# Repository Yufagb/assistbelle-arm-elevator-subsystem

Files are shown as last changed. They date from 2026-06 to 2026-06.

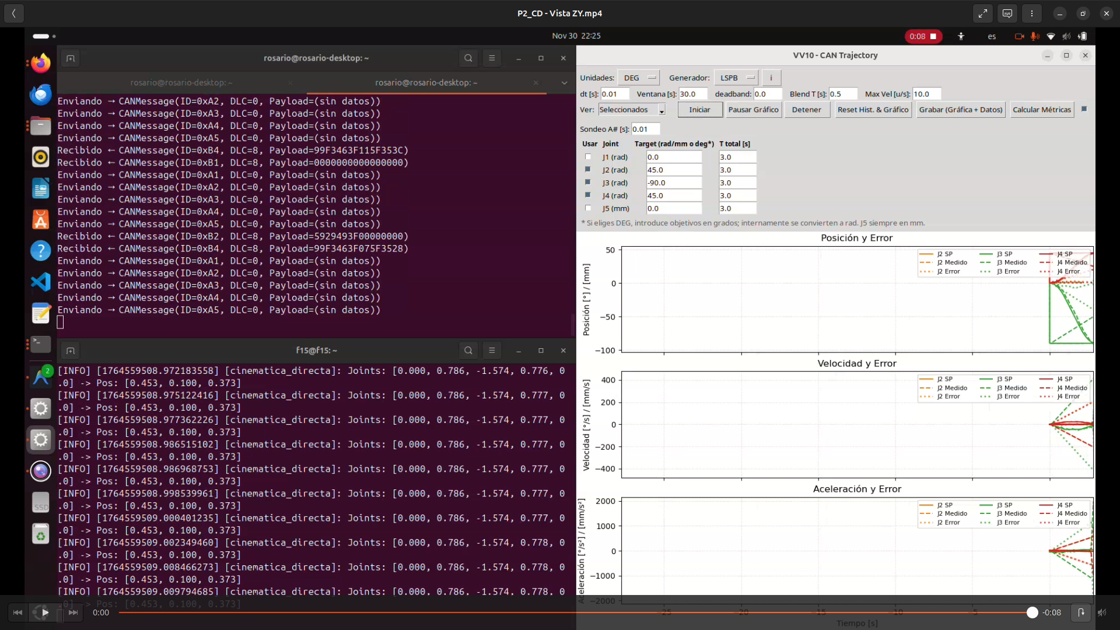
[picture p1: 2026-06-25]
validation/kinematics_tests/figures/CD_P2_Consola.png

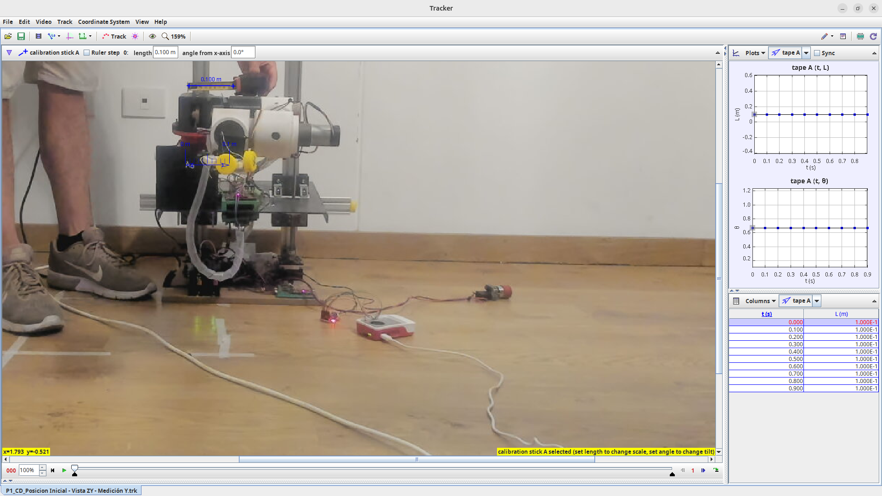
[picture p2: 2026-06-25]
validation/kinematics_tests/figures/CD_P1_VistaZY_MedicionY.png

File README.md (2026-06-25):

<!-- SPDX-License-Identifier: CC-BY-4.0 -->

# Assistbelle robotic arm and elevator subsystem

Open-source HardwareX publication package for the **robotic arm and vertical elevator subsystem** of Assistbelle, intended for controlled laboratory experiments on the manipulation and transport of medical supplies.

This repository contains the hardware documentation, firmware, ROS 2 software, electronics documentation, validation material and publication support files needed to reproduce and evaluate the arm/elevator subsystem.

## Authors

- Yuri Fabian Vilela Obando
- Luciano Matteo Vergani Api

## Scope

This repository covers:

- robotic arm subsystem;
- vertical elevator / prismatic axis;
- ESP32 firmware for distributed joint control;
- CAN / SocketCAN communication;
- ROS 2 control and validation utilities;
- electronics documentation, pinouts, power distribution and schematics;
- bill of materials (BOM);
- validation documentation and curated evidence structure;
- documentation and paper-support material for HardwareX.

## Out of scope

The current public package does **not** cover:

- autonomous navigation;
- the complete mobile base;
- the storage module;
- real clinical validation or certified medical-device use.

The system must be interpreted as a **laboratory prototype** for controlled validation, not as a clinically approved device.

## Quick start

This flow verifies the ROS 2 package and the CAN bridge using a virtual CAN interface (`vcan`).

```bash
git clone https://github.com/Yufagb/assistbelle-arm-elevator-subsystem.git
cd assistbelle-arm-elevator-subsystem/ros2_ws
source /opt/ros/jazzy/setup.bash
pip install -r ../requirements.txt
rm -rf build install log
colcon build --packages-select can_comm_pkg
source install/setup.bash
sudo modprobe vcan
sudo ip link add dev can0 type vcan 2>/dev/null || true
sudo ip link set up can0
ros2 run can_comm_pkg can_node
```

Expected output:

```text
CANNode iniciado y suscrito a /can_command
```

For ESP32 firmware, use [`firmware/ESP_IDF_BUILD_GUIDE.md`](firmware/ESP_IDF_BUILD_GUIDE.md).

## Repository structure

```text
assistbelle-arm-elevator-subsystem/
├── README.md
├── LICENSE
├── CITATION.cff
├── requirements.txt
├── docs/
├── electronics/
├── firmware/
├── hardware/
├── paper/
├── ros2_ws/
├── software/
└── validation/
```

| Path | Purpose |
|---|---|
| [`docs/`](docs/) | General documentation, operation, safety, calibration, troubleshooting, BOM and checklists. |
| [`electronics/`](electronics/) | Schematics, wiring diagrams, power distribution, pinout tables and electronics images. |
| [`firmware/`](firmware/) | ESP32 firmware organized by joint/elevator node. |
| [`hardware/`](hardware/) | Mechanical CAD, STEP, STL, drawings, photos and fasteners. |
| [`paper/`](paper/) | Figures, tables, references and manuscript-support material. |
| [`ros2_ws/`](ros2_ws/) | ROS 2 workspace and `can_comm_pkg`. |
| [`software/`](software/) | Auxiliary software notes or scripts outside the ROS 2 workspace. |
| [`validation/`](validation/) | Curated validation data, media, figures and test summaries. |

Legacy folders from the development repository, such as `Codigo_esp32/` or `resultados/`, are not part of the recommended public structure. Useful firmware should be kept under [`firmware/`](firmware/), and curated evidence should be kept under [`validation/`](validation/).

## Documentation map

| Document | Description |
|---|---|
| [`docs/README.md`](docs/README.md) | Documentation index. |
| [`docs/project_status.md`](docs/project_status.md) | Current project status and immediate pending items. |
| [`docs/repository_audit.md`](docs/repository_audit.md) | Repository audit and closure criteria. |
| [`docs/repo_cleanup_audit.md`](docs/repo_cleanup_audit.md) | Cleanup audit, placeholder checks and local validation commands. |
| [`docs/repository_structure.md`](docs/repository_structure.md) | Repository organization rules. |
| [`docs/hardwarex_master_checklist.md`](docs/hardwarex_master_checklist.md) | Master checklist for HardwareX completion. |
| [`docs/publication_checklist.md`](docs/publication_checklist.md) | Publication-oriented checklist. |
| [`docs/operation_manual.md`](docs/operation_manual.md) | Operation steps for ROS 2, SocketCAN and ESP-IDF. |
| [`docs/calibration_manual.md`](docs/calibration_manual.md) | Initial calibration procedure. |
| [`docs/safety_notes.md`](docs/safety_notes.md) | Safety notes for laboratory operation. |
| [`docs/troubleshooting.md`](docs/troubleshooting.md) | Common errors and fixes. |
| [`docs/ros2_entrypoints_validation.md`](docs/ros2_entrypoints_validation.md) | ROS 2 command validation routine. |
| [`docs/bom/README.md`](docs/bom/README.md) | BOM index, source traceability and reading order. |
| [`docs/bom/hardwarex_elevator_bom_final.md`](docs/bom/hardwarex_elevator_bom_final.md) | Readable HardwareX elevator BOM summary for GitHub reviewers. |
| [`docs/bom/hardwarex_elevator_bom_final.csv`](docs/bom/hardwarex_elevator_bom_final.csv) | Complete machine-readable HardwareX elevator BOM. |
| [`docs/license_overview.md`](docs/license_overview.md) | Multi-license policy. |

## Current status

| Area | Status | Reference |
|---|---|---|
| Repository organization | Advanced | [`docs/repository_structure.md`](docs/repository_structure.md), [`docs/repo_cleanup_audit.md`](docs/repo_cleanup_audit.md) |
| ESP32 firmware J1-J4 | Included; previously compiled locally | [`firmware/esp32_joint_node/`](firmware/esp32_joint_node/) |
| ESP32 firmware J5 / TB6600 | Included; CAN `B5` payload closeout pending physical validation | [`firmware/esp32_stepper_node/J5_tb6600/`](firmware/esp32_stepper_node/J5_tb6600/), [`firmware/can_protocol/can_messages.md`](firmware/can_protocol/can_messages.md) |
| ROS 2 / CAN bridge | Builds and starts with `vcan`; clean-clone entry-point validation pending | [`ros2_ws/`](ros2_ws/), [`docs/ros2_entrypoints_validation.md`](docs/ros2_entrypoints_validation.md) |
| ESP32 pinouts | Documented | [`electronics/pinout_tables/esp32_pinout_table.md`](electronics/pinout_tables/esp32_pinout_table.md) |
| Raspberry Pi + MCP2515 | Documented and included in BOM/CAD | [`electronics/pinout_tables/raspberry_pi_mcp2515.md`](electronics/pinout_tables/raspberry_pi_mcp2515.md), [`docs/bom/hardwarex_elevator_bom_final.md`](docs/bom/hardwarex_elevator_bom_final.md) |
| CAN protocol | Documented; J5 `C5` compatible and `B5` final decision pending | [`firmware/can_protocol/can_messages.md`](firmware/can_protocol/can_messages.md) |
| BOM | Updated for the current elevator package: 32 item rows, estimated total USD 484.78 | [`docs/bom/hardwarex_elevator_bom_final.md`](docs/bom/hardwarex_elevator_bom_final.md), [`docs/bom/hardwarex_elevator_bom_final.csv`](docs/bom/hardwarex_elevator_bom_final.csv) |
| Schematics/electronics | Documented in text; physical connector data/photos pending | [`electronics/`](electronics/), [`electronics/wiring_diagrams/connector_table.md`](electronics/wiring_diagrams/connector_table.md) |
| Mechanical CAD / STEP / STL / drawings | Advanced for v60 working snapshot; prototype photos deferred | [`hardware/`](hardware/), [`hardware/design_files_index.md`](hardware/design_files_index.md) |
| Paper material | Outline, tables, data availability and Mermaid figure drafts created | [`paper/`](paper/) |
| Validation | Structure ready; curated media/CSV/plots pending | [`validation/validation_plan.md`](validation/validation_plan.md) |

## Firmware ESP32

The final ESP32 firmware is kept in [`firmware/`](firmware/):

```text
firmware/
├── ESP_IDF_BUILD_GUIDE.md
├── can_protocol/
├── esp32_joint_node/
│   ├── J1/
│   ├── J2/
│   ├── J3/
│   └── J4/
└── esp32_stepper_node/
    └── J5_tb6600/
```

Example build command:

```bash
source /path/to/esp-idf/export.sh
cd firmware/esp32_joint_node/J1
idf.py set-target esp32
idf.py build
```

## ROS 2

The ROS 2 workspace is kept in [`ros2_ws/`](ros2_ws/):

```bash
cd ros2_ws
source /opt/ros/jazzy/setup.bash
rm -rf build install log
colcon build --packages-select can_comm_pkg
source install/setup.bash
```

Main commands to validate:

```bash
ros2 run can_comm_pkg can_node
ros2 run can_comm_pkg control_teclado
ros2 run can_comm_pkg can_traj
ros2 run can_comm_pkg can_slider
ros2 run can_comm_pkg ik_node
ros2 run can_comm_pkg j5_ramp
ros2 run can_comm_pkg j5_trap
```

## Electronics

Electronics documentation is organized in [`electronics/`](electronics/):

```text
electronics/
├── images/
├── pinout_tables/
├── power_distribution/
├── schematics/
└── wiring_diagrams/
```

Current documentation includes ESP32 pinouts, Raspberry Pi + MCP2515 wiring, CAN/power bus notes, power-distribution notes, a working connector table and a schematics index. Final schematic filenames/exports, electronics photos and physical connector details remain pending.

## Mechanical hardware

Mechanical design files are organized as:

```text
hardware/
├── cad/
├── step/
├── stl/
├── drawings/
├── photos/
└── fasteners/
```

The current uploaded CAD package is the **v60 working snapshot** and includes editable Fusion 360 archive, full STEP export, STL files for custom fabricated/printed parts, PDF drawings and DXF cutting files. Physical prototype photos are deferred until the robot is accessible again.

See [`hardware/design_files_index.md`](hardware/design_files_index.md) for the current file inventory.

## Validation

Validation material is organized in [`validation/`](validation/):

```text
validation/
├── validation_plan.md
├── figures/
├── joint_motion_tests/
├── kinematics_tests/
├── media/
├── perception_tests/
└── pick_and_place_tests/
```

Pending work includes curated videos, final CSV files, figures, physical CAN validation, pick-and-place validation and perception validation.

## Bill of materials

The readable HardwareX elevator BOM is available at:

```text
docs/bom/hardwarex_elevator_bom_final.md
```

The complete machine-readable CSV is available at:

```text
docs/bom/hardwarex_elevator_bom_final.csv
```

Current BOM snapshot:

- 32 BOM item rows + 1 estimated-total row.
- Source workbook: `ASM_Elevator_System_HardwareX_BOM`.
- Source tab: `BOM_Final_Clean`.
- Current uploaded CAD working snapshot: v60.
- Included CAD electronics: Raspberry Pi 5, MCP2515 CAN-SPI module and two TB6600 drivers.
- Estimated product/material total: **USD 484.78**.
- Shipping, customs, taxes and marketplace price changes are excluded.
- Raspberry Pi 5 exact seller/product is still pending confirmation.

The previous [`docs/bom_template.csv`](docs/bom_template.csv) is retained as a historical Spanish/PEN reference and should not be treated as the main HardwareX elevator BOM.

## License

This repository uses a multi-license structure suitable for a HardwareX open-source hardware submission:

| Directory / asset type | License | License text |
|---|---|---|
| [`hardware/`](hardware/) | CERN-OHL-S v2.0 | [`LICENSES/CERN-OHL-S-2.0.txt`](LICENSES/CERN-OHL-S-2.0.txt) |
| [`electronics/`](electronics/) | CERN-OHL-S v2.0 | [`LICENSES/CERN-OHL-S-2.0.txt`](LICENSES/CERN-OHL-S-2.0.txt) |
| [`firmware/`](firmware/), [`ros2_ws/`](ros2_ws/), [`software/`](software/) | Apache-2.0 | [`LICENSES/Apache-2.0.txt`](LICENSES/Apache-2.0.txt) |
| Validation scripts and utilities | Apache-2.0 | [`LICENSES/Apache-2.0.txt`](LICENSES/Apache-2.0.txt) |
| [`docs/`](docs/), [`paper/`](paper/), images, figures, manuals and assembly instructions | CC-BY-4.0 | [`LICENSES/CC-BY-4.0.txt`](LICENSES/CC-BY-4.0.txt) |

The root [`LICENSE`](LICENSE) file summarizes this policy. See [`docs/license_overview.md`](docs/license_overview.md) for details.

## Remaining HardwareX closure items

- [ ] Confirm final schematic filenames and exports.
- [ ] Add electronics photos.
- [ ] Confirm physical connector pin order, wire colors and cable gauges.
- [ ] Confirm TB6600 supply voltage and exact Dell PSU model.
- [ ] Add physical prototype photos once the robot is accessible.
- [ ] Validate all ROS 2 entry points from a clean clone.
- [ ] Curate validation videos, CSV files and figures.
- [ ] Freeze final CAD/BOM release and tag the GitHub release used by the manuscript.

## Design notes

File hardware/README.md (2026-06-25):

<!-- SPDX-License-Identifier: CC-BY-4.0 -->

# Hardware

Mechanical design package for the Assistbelle robotic arm and elevator subsystem.

This folder contains the mechanical files needed to reproduce the current elevator package. Do not place ROS 2 code, firmware or validation data here.

## Upload guide

Use [`design_files_index.md`](design_files_index.md) to see the current mechanical file inventory. The previous step-by-step upload plan is kept in [`design_files_upload_plan.md`](design_files_upload_plan.md) as workflow history.

## Current CAD snapshot

The current uploaded CAD snapshot is **v60**. It is a working snapshot, not yet the final frozen HardwareX release.

| File | Status | Notes |
|---|---|---|
| [`cad/complete_robot/ASM_Elevator_System_v60.f3z`](cad/complete_robot/ASM_Elevator_System_v60.f3z) | Uploaded via Git LFS | Editable Fusion 360 archive. |
| [`step/ASM_Elevator_System_v60.step`](step/ASM_Elevator_System_v60.step) | Uploaded via Git LFS | Full neutral STEP assembly. |
| [`stl/FAB_ACT_002_NEMA23_Mounting_Plate_ABS_v60.stl`](stl/FAB_ACT_002_NEMA23_Mounting_Plate_ABS_v60.stl) | Uploaded via Git LFS | NEMA 23 mounting plate STL. |
| [`stl/FAB_GUI_002_Spacer_Block_ABS_Gray_v60.stl`](stl/FAB_GUI_002_Spacer_Block_ABS_Gray_v60.stl) | Uploaded via Git LFS | Spacer block STL. |
| [`drawings/FAB_STR_001_Base_Plate_356x356x15_MDF_v60.pdf`](drawings/FAB_STR_001_Base_Plate_356x356x15_MDF_v60.pdf) | Uploaded | MDF base plate drawing. |
| [`drawings/FAB_STR_002_Top_Plate_420x400x3_StainlessSteel_v60.pdf`](drawings/FAB_STR_002_Top_Plate_420x400x3_StainlessSteel_v60.pdf) | Uploaded | Stainless-steel top plate drawing. |
| [`drawings/FAB_GUI_001_Gantry_Plate_127x88x3_StainlessSteel_v60.pdf`](drawings/FAB_GUI_001_Gantry_Plate_127x88x3_StainlessSteel_v60.pdf) | Uploaded | Stainless-steel gantry plate drawing. |
| [`drawings/FAB_STR_002_Top_Plate_420x400x3_StainlessSteel_v60.dxf`](drawings/FAB_STR_002_Top_Plate_420x400x3_StainlessSteel_v60.dxf) | Uploaded via Git LFS | Top plate cutting DXF. |
| [`drawings/FAB_GUI_001_Gantry_Plate_127x88x3_StainlessSteel_v60.dxf`](drawings/FAB_GUI_001_Gantry_Plate_127x88x3_StainlessSteel_v60.dxf) | Uploaded via Git LFS | Gantry plate cutting DXF. |

## Canonical structure

| Folder | Content |
|---|---|
| `cad/` | Editable CAD files. |
| `step/` | Neutral STEP exports. |
| `stl/` | 3D-printable or fabricated-part exports. |
| `drawings/` | Mechanical drawings and DXF cutting files. |
| `photos/` | Photos of the assembled mechanical system. Deferred until robot access. |
| `fasteners/` | Screws, nuts, bearings, profiles and standard mechanical parts. |

## CAD substructure

| Folder | Content |
|---|---|
| `cad/complete_robot/` | Complete assembly. |
| `cad/arm/` | 4-DOF arm, joints and links, if exported separately. |
| `cad/elevator/` | Vertical elevator mechanism, if exported separately. |
| `cad/gripper/` | End effector or gripper, if exported separately. |
| `cad/mounts/` | Mounts, adapters and brackets, if exported separately. |

## Legacy folders

Older folders such as `CAD_editable`, `STEP` and `STL` were created during previous passes. For new files, use only the canonical lowercase folders: `cad`, `step` and `stl`.

## Minimum publication requirement

Each custom mechanical part should have at least one of the following:

- editable CAD file;
- STEP export;
- STL file if it is 3D printed;
- drawing with dimensions;
- DXF file if it is a cut plate;
- photo showing the part installed when physical access is available.

## Remaining mechanical work

- Add physical prototype photos once the robot is accessible.
- Optionally add subsystem STEP exports before the final frozen release.
- Re-export changed CAD/STEP/STL/PDF/DXF files if the snapshot advances beyond v60.
- Freeze the final CAD/BOM version before HardwareX submission.

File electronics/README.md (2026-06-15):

<!-- SPDX-License-Identifier: CERN-OHL-S-2.0 -->

# Electronics

Electrical and electronics documentation for the Assistbelle robotic arm and elevator subsystem.

## Index

- [Folder map](#folder-map)
- [Current status](#current-status)
- [Main documents](#main-documents)
- [Closure pending items](#closure-pending-items)

## Folder map

| Folder | Content | Status |
|---|---|---|
| [`schematics/`](schematics/) | Electrical schematics and visual exports. | In progress |
| [`wiring_diagrams/`](wiring_diagrams/) | Practical wiring documentation and connector tables. | Partial |
| [`pinout_tables/`](pinout_tables/) | ESP32, Raspberry Pi and CAN-module pinout tables. | Advanced |
| [`power_distribution/`](power_distribution/) | Power supply, 12 V actuator rail, 5 V logic rail and grounding notes. | Updated, pending measurements/photos |
| [`images/`](images/) | Electronics photos and captures. | Pending final photos |

## Current status

| Block | Status | Reference |
|---|---|---|
| ESP32 node pinout | Documented | [`pinout_tables/esp32_pinout_table.md`](pinout_tables/esp32_pinout_table.md) |
| Raspberry Pi + MCP2515 | Documented | [`pinout_tables/raspberry_pi_mcp2515.md`](pinout_tables/raspberry_pi_mcp2515.md) |
| Main bus | Documented in text | [`wiring_diagrams/bus_principal.md`](wiring_diagrams/bus_principal.md) |
| Controller nodes | Driver assignment documented, physical verification pending | [`wiring_diagrams/nodos_controladores.md`](wiring_diagrams/nodos_controladores.md) |
| Connector table | Template created, physical connector data pending | [`wiring_diagrams/connector_table.md`](wiring_diagrams/connector_table.md) |
| Power distribution | Updated with Dell 12 V supply, LM2596S 5 V converter and panic-button behavior | [`power_distribution/power_summary.md`](power_distribution/power_summary.md) |
| Schematics | Structure and review criteria ready | [`schematics/schematics_index.md`](schematics/schematics_index.md) |

## Main documents

- [`schematics/README.md`](schematics/README.md)
- [`schematics/schematics_index.md`](schematics/schematics_index.md)
- [`pinout_tables/esp32_pinout_table.md`](pinout_tables/esp32_pinout_table.md)
- [`pinout_tables/raspberry_pi_mcp2515.md`](pinout_tables/raspberry_pi_mcp2515.md)
- [`wiring_diagrams/bus_principal.md`](wiring_diagrams/bus_principal.md)
- [`wiring_diagrams/nodos_controladores.md`](wiring_diagrams/nodos_controladores.md)
- [`wiring_diagrams/connector_table.md`](wiring_diagrams/connector_table.md)
- [`power_distribution/power_summary.md`](power_distribution/power_summary.md)

## Closure pending items

- [ ] Confirm final schematic filenames and exports.
- [ ] Export each editable schematic to PDF/PNG.
- [ ] Add real electronics photos in [`images/`](images/).
- [ ] Fill final connector table from physical inspection.
- [ ] Confirm Dell server power-supply model.
- [ ] Measure 12 V actuator rail current during representative tests.
- [ ] Measure 5 V logic rail current.
- [ ] Verify consistency between schematics, connector table, pinouts, firmware and BOM.

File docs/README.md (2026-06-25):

<!-- SPDX-License-Identifier: CC-BY-4.0 -->

# Documentación del proyecto

Esta carpeta concentra la documentación general del paquete HardwareX de Assistbelle.

## Índice

- [Lectura recomendada](#lectura-recomendada)
- [Archivos principales](#archivos-principales)
- [Relación con otras carpetas](#relación-con-otras-carpetas)
- [Estado actual](#estado-actual)
- [Criterios de documentación](#criterios-de-documentación)

## Lectura recomendada

1. [`project_status.md`](project_status.md): estado actual del repositorio.
2. [`repository_audit.md`](repository_audit.md): auditoría de avance y pendientes.
3. [`repo_cleanup_audit.md`](repo_cleanup_audit.md): auditoría de limpieza, placeholders y archivos generados.
4. [`repository_structure.md`](repository_structure.md): reglas de organización.
5. [`hardwarex_master_checklist.md`](hardwarex_master_checklist.md): checklist maestro.
6. [`publication_checklist.md`](publication_checklist.md): checklist de publicación.
7. [`operation_manual.md`](operation_manual.md): operación básica y comandos.
8. [`ros2_entrypoints_validation.md`](ros2_entrypoints_validation.md): validación de comandos ROS 2.
9. [`calibration_manual.md`](calibration_manual.md): calibración.
10. [`safety_notes.md`](safety_notes.md): seguridad.
11. [`troubleshooting.md`](troubleshooting.md): problemas comunes.
12. [`bom/README.md`](bom/README.md): índice de BOM HardwareX.
13. [`bom/hardwarex_elevator_bom_final.md`](bom/hardwarex_elevator_bom_final.md): BOM legible para revisión.
14. [`bom/hardwarex_elevator_bom_final.csv`](bom/hardwarex_elevator_bom_final.csv): BOM machine-readable.
15. [`procurement/README.md`](procurement/README.md): compras y evidencia pública curada.
16. [`license_overview.md`](license_overview.md): licencias y citación.

## Archivos principales

| Archivo | Propósito |
|---|---|
| [`project_status.md`](project_status.md) | Estado real del proyecto por área. |
| [`repository_audit.md`](repository_audit.md) | Revisión general, pendientes y criterio de cierre. |
| [`repo_cleanup_audit.md`](repo_cleanup_audit.md) | Auditoría de limpieza del repo y comandos locales de validación. |
| [`repository_structure.md`](repository_structure.md) | Reglas de carpetas y migración. |
| [`hardwarex_master_checklist.md`](hardwarex_master_checklist.md) | Checklist de cierre HardwareX. |
| [`publication_checklist.md`](publication_checklist.md) | Checklist extendido de publicación. |
| [`operation_manual.md`](operation_manual.md) | Secuencia de compilación, CAN y ejecución. |
| [`calibration_manual.md`](calibration_manual.md) | Calibración inicial. |
| [`safety_notes.md`](safety_notes.md) | Seguridad del prototipo. |
| [`troubleshooting.md`](troubleshooting.md) | Solución de errores comunes. |
| [`ros2_entrypoints_validation.md`](ros2_entrypoints_validation.md) | Pruebas de entry points ROS 2. |
| [`bom/README.md`](bom/README.md) | Índice de BOM, trazabilidad y orden de lectura. |
| [`bom/hardwarex_elevator_bom_final.md`](bom/hardwarex_elevator_bom_final.md) | BOM HardwareX legible para GitHub. |
| [`bom/hardwarex_elevator_bom_final.csv`](bom/hardwarex_elevator_bom_final.csv) | BOM HardwareX completa en CSV. |
| [`procurement/README.md`](procurement/README.md) | Política pública de evidencia de compras. |
| [`procurement/purchase_log_public.csv`](procurement/purchase_log_public.csv) | Log público y curado de compras/procurement. |
| [`license_overview.md`](license_overview.md) | Licencias, `LICENSE` y `CITATION.cff`. |

## Relación con otras carpetas

| Carpeta | Documentación relacionada |
|---|---|
| [`../firmware/`](../firmware/) | [`../firmware/README.md`](../firmware/README.md), [`../firmware/ESP_IDF_BUILD_GUIDE.md`](../firmware/ESP_IDF_BUILD_GUIDE.md), [`../firmware/can_protocol/can_messages.md`](../firmware/can_protocol/can_messages.md) |
| [`../electronics/`](../electronics/) | [`../electronics/README.md`](../electronics/README.md), [`../electronics/schematics/schematics_index.md`](../electronics/schematics/schematics_index.md), [`../electronics/pinout_tables/esp32_pinout_table.md`](../electronics/pinout_tables/esp32_pinout_table.md), [`../electronics/wiring_diagrams/connector_table.md`](../electronics/wiring_diagrams/connector_table.md) |
| [`../ros2_ws/`](../ros2_ws/) | Workspace ROS 2 y paquete `can_comm_pkg`. |
| [`../hardware/`](../hardware/) | [`../hardware/README.md`](../hardware/README.md), [`../hardware/design_files_index.md`](../hardware/design_files_index.md) y subcarpetas CAD/STEP/STL/drawings. |
| [`../validation/`](../validation/) | [`../validation/validation_plan.md`](../validation/validation_plan.md) y evidencias curadas. |
| [`../paper/`](../paper/) | [`../paper/manuscript_outline.md`](../paper/manuscript_outline.md), [`../paper/data_availability_statement.md`](../paper/data_availability_statement.md), figuras y tablas del manuscrito. |

## Estado actual

- Firmware ESP32 J1-J5 migrado e incluido.
- Pinout ESP32 documentado.
- Protocolo CAN documentado; `C5` es compatible con ROS 2 y `B5` queda pendiente de cierre físico/firmware.
- Raspberry Pi + MCP2515 documentado.
- ROS 2 compila localmente y `can_node` inicia con `can0` virtual; falta clean-clone entry-point validation.
- BOM HardwareX activa: 32 ítems + total estimado USD 484.78.
- Evidencia pública de compras creada en [`procurement/`](procurement/).
- Esquemáticos y electrónica documentados en texto; fotos y verificación física de conectores quedan pendientes.
- CAD/STEP/STL/PDF/DXF mecánicos del snapshot v60 cargados; fotos físicas del robot quedan diferidas.
- Manuscript outline, data availability statement, design-files table, BOM table y diagramas Mermaid draft creados en [`../paper/`](../paper/).

## Criterios de documentación

- No duplicar información técnica si puede enlazarse.
- Mantener ROS 2 dentro de [`../ros2_ws/`](../ros2_ws/).
- Mantener firmware ESP32 dentro de [`../firmware/`](../firmware/).
- Mantener electrónica en [`../electronics/`](../electronics/).
- Mantener mecánica en [`../hardware/`](../hardware/).
- Mantener evidencias curadas en [`../validation/`](../validation/).
- Mantener comprobantes brutos o documentos financieros fuera del repositorio público salvo que estén revisados y redactados.
- Antes del envío final, traducir documentación clave al inglés técnico.

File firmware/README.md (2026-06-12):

# Firmware ESP32

Esta carpeta contiene los proyectos ESP-IDF usados para programar los microcontroladores ESP32 del robot.

## Estructura

- ESP_IDF_BUILD_GUIDE.md: guia para compilar y programar.
- import_firmware_from_zips.sh: script auxiliar para importar los ZIP originales.
- can_protocol: documentacion de mensajes CAN.
- esp32_joint_node: nodos J1, J2, J3 y J4.
- esp32_stepper_node: nodo J5 del elevador con TB6600.

## Nodos disponibles

| Nodo | Subsistema | Carpeta | Estado |
|---|---|---|---|
| J1 | Base | esp32_joint_node/J1 | Compila localmente |
| J2 | Hombro | esp32_joint_node/J2 | Compila localmente |
| J3 | Codo | esp32_joint_node/J3 | Compila localmente |
| J4 | Muneca y gripper | esp32_joint_node/J4 | Compila localmente |
| J5 | Elevador TB6600 | esp32_stepper_node/J5_tb6600 | Compila localmente |

## Guia principal

Usar ESP_IDF_BUILD_GUIDE.md para cargar ESP-IDF, compilar, flashear y abrir los proyectos con VS Code.

## Dependencia externa

ESP-IDF no se versiona dentro del repositorio porque es una dependencia pesada. Debe estar instalado fuera del repositorio, por ejemplo en el disco externo donde se tenga ESP_IDF_CONTAINER.

## Relacion con electronica

- Pines por nodo: electronics/pinout_tables/esp32_pinout_table.md.
- Protocolo CAN: firmware/can_protocol/can_messages.md.
- Bus principal: electronics/wiring_diagrams/bus_principal.md.
- Nodos controladores: electronics/wiring_diagrams/nodos_controladores.md.

## Archivos que no deben subirse

No versionar salidas de compilacion ni configuraciones locales: build, .vscode, .devcontainer, .clangd, binarios, mapas, ELF ni sdkconfig.old.

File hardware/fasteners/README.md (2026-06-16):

<!-- SPDX-License-Identifier: CERN-OHL-S-2.0 -->

# Fasteners and standard structural parts

This folder documents screws, nuts, bearings, rods, V-slot profiles, brackets, couplings and other standard mechanical parts used or purchased for the Assistbelle robotic arm and elevator subsystem.

## Files

| File | Purpose | Status |
|---|---|---|
| [`structural_profiles_table.csv`](structural_profiles_table.csv) | Reconciliation table for V-slot profiles, V-slot brackets, wheel kits, KP-08/KFL08 supports and related structural purchases. | Created from BOM and procurement evidence; physical verification pending. |
| `fasteners_table.csv` | Final installed screws, nuts, washers and small fasteners. | Pending. |
| `bearings_table.csv` | Final installed bearings and supports. | Pending. |

## Current V-slot / structural evidence summary

The current evidence has one important mismatch that must be resolved before freezing the HardwareX BOM:

| Evidence | Profile information | Status |
|---|---|---|
| Active BOM line `BOM-036` | `Perfil V-Slot 2040`, total 170 cm, described as 60 cm + 60 cm + 50 cm. | Active BOM baseline; verify on robot/CAD. |
| Procurement line `PRC-030` | `Perfil V-Slot 2020`, 70 cm x4 and 35 cm x2, total 350 cm. | Purchased structural material; reconcile before final BOM. |

Do not overwrite the active BOM quantity until the physical prototype and CAD confirm which profile family and lengths are installed.

## Physical verification needed

- [ ] Confirm whether the final frame uses V-Slot 2040, V-Slot 2020, or both.
- [ ] Measure final installed profile lengths.
- [ ] Photograph the installed V-slot profiles.
- [ ] Confirm installed quantity of 90-degree brackets and double L brackets.
- [ ] Confirm installed quantity of M5 screws and 2020 T-nuts.
- [ ] Confirm whether the 6 mm belt/NEMA17/A4988 kit was only for testing or belongs to another subsystem.
- [ ] Update `fasteners_table.csv` and `bearings_table.csv` after inspection.

## Related documents

- [`../../docs/bom_template.csv`](../../docs/bom_template.csv)
- [`../../docs/procurement/purchase_log_public.csv`](../../docs/procurement/purchase_log_public.csv)
- [`../../docs/procurement/usage_reconciliation.md`](../../docs/procurement/usage_reconciliation.md)

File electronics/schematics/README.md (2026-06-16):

<!-- SPDX-License-Identifier: CERN-OHL-S-2.0 -->

# Electrical schematics

This folder contains the electrical schematic PDFs for the Assistbelle robotic arm and elevator subsystem.

The schematics document the main power/CAN bus, Raspberry Pi to MCP2515 interface, ESP32-based DC motor controller nodes, IBT-2-based DC motor controller nodes and the J5 stepper/elevator controller.

## Available schematic PDFs

| File | Subsystem | Main content | HardwareX status |
|---|---|---|---|
| `Main Bus.pdf` | Main power and CAN bus | 12V, P_GND, 5V, S_GND, CANH, CANL, subsystem branches and RT1/RT2 120-ohm CAN terminations. | Reviewed; physical implementation still pending. |
| `RASPBERRYPI_MCP2515.pdf` | Raspberry Pi to MCP2515 interface | Raspberry Pi 40-pin header, MCP2515 10-pin header, SPI, interrupt, CAN connector and 5V power connector. | Reviewed; final implementation uses 5 V module power and must preserve Raspberry Pi 3.3 V logic compatibility. |
| `DC_MOTOR_DRIVER_SCH.pdf` | DRV8871 DC motor controller | ESP32 NodeMCU, SN65HVD230DR, DRV8871DDA, CAN header, power headers and motor/encoder header. | Reviewed; intended for J1/J4 documentation, physical assignment pending. |
| `DC_MOTOR_DRIVER_SCH_IBT2.pdf` | IBT-2 DC motor controller | ESP32 NodeMCU, SN65HVD230DR, IBT-2 interface, CAN header, power headers and motor/encoder header. | Reviewed; intended for J2/J3 documentation, physical assignment pending. |
| `Stepper Driver v7.pdf` | J5 stepper/elevator controller | ESP32 NodeMCU, CAN transceiver, J_CAN, J_DRIVERS with ENA/DIR/PUL and J_5V. | Reviewed; physical assignment pending. |

## Extracted design coverage

| Requirement | Covered by | Notes |
|---|---|---|
| 12 V actuator rail | `Main Bus.pdf`, motor-driver schematics | Main Bus separates 12V and P_GND. |
| 5 V logic rail | `Main Bus.pdf`, `RASPBERRYPI_MCP2515.pdf`, motor-driver schematics, `Stepper Driver v7.pdf` | Final implementation uses 5 V for the MCP2515 module and 5 V logic distribution from the LM2596S rail. |
| Separate power/signal grounds | `Main Bus.pdf` | Main Bus labels P_GND and S_GND separately. |
| CANH/CANL bus | All five schematics | CAN connector or SN65HVD230DR shown in controller sheets. |
| CAN termination | `Main Bus.pdf` | RT1 and RT2 are shown as 120-ohm terminations. |
| Raspberry Pi + MCP2515 | `RASPBERRYPI_MCP2515.pdf` | Includes SPI, INT_CAN, 5 V power connector and CAN connector. |
| DRV8871 DC motor node | `DC_MOTOR_DRIVER_SCH.pdf` | Includes DRV8871DDA and ILIM path. |
| IBT-2 DC motor node | `DC_MOTOR_DRIVER_SCH_IBT2.pdf` | Includes IBT2_CONN, IBT_POWER_HEADER and IBT_MOTOR_HEADER. |
| J5 stepper/elevator node | `Stepper Driver v7.pdf` | Includes PUL, DIR and ENA signals. |

## Files derived from this schematic review

The following repository documents use information extracted from these PDFs:

- [`schematics_index.md`](schematics_index.md): indexed schematic summary and extracted connector/component information.
- [`../wiring_diagrams/connector_table.md`](../wiring_diagrams/connector_table.md): connector table extracted from the schematic PDFs.
- [`../wiring_diagrams/nodos_controladores.md`](../wiring_diagrams/nodos_controladores.md): node-to-driver assignment and physical verification checklist.
- [`../power_distribution/power_summary.md`](../power_distribution/power_summary.md): power architecture summary.

## Physical verification still required

Before final HardwareX submission, verify on the real robot:

- [ ] the exact location of RT1 and RT2 CAN termination resistors;
- [ ] the MCP2515 module is powered from 5 V and safely interfaces with Raspberry Pi 3.3 V SPI/INT logic;
- [ ] the physical driver assignment: J1 DRV8871, J2 IBT-2, J3 IBT-2, J4 DRV8871 + servo, J5 TB6600;
- [ ] connector models, pin order, wire colors and cable gauges;
- [ ] the actual panic-button wiring path for actuator power cut-off;
- [ ] final photos for [`../images/`](../images/).

## Export and naming recommendations

For final publication, keep the current PDFs and optionally export PNG previews with these names:

| Optional PNG export | Source PDF |
|---|---|
| `schematic_main_bus.png` | `Main Bus.pdf` |
| `schematic_raspberrypi_mcp2515.png` | `RASPBERRYPI_MCP2515.pdf` |
| `schematic_drv8871_node.png` | `DC_MOTOR_DRIVER_SCH.pdf` |
| `schematic_ibt2_node.png` | `DC_MOTOR_DRIVER_SCH_IBT2.pdf` |
| `schematic_stepper_j5_node.png` | `Stepper Driver v7.pdf` |

If editable KiCad or EDA source files exist, keep them together with the PDF/PNG exports in this folder.

## Related documents

- [`../README.md`](../README.md)
- [`schematics_index.md`](schematics_index.md)
- [`../pinout_tables/esp32_pinout_table.md`](../pinout_tables/esp32_pinout_table.md)
- [`../pinout_tables/raspberry_pi_mcp2515.md`](../pinout_tables/raspberry_pi_mcp2515.md)
- [`../wiring_diagrams/bus_principal.md`](../wiring_diagrams/bus_principal.md)
- [`../wiring_diagrams/nodos_controladores.md`](../wiring_diagrams/nodos_controladores.md)
- [`../wiring_diagrams/connector_table.md`](../wiring_diagrams/connector_table.md)
- [`../power_distribution/power_summary.md`](../power_distribution/power_summary.md)

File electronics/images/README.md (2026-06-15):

<!-- SPDX-License-Identifier: CC-BY-4.0 -->

# Electronics images

This folder stores the final electronics photos and schematic captures used to document the Assistbelle robotic arm and elevator subsystem for HardwareX.

## Purpose

The photos in this folder should make the electronics reproducible by showing the real implementation, connector orientation, driver assignment and wiring layout.

## Required photo set

| Image filename | Content to capture | Required evidence | Status |
|---|---|---|---|
| `electronics_overview.jpg` | General electronics layout. | Full view of power supply, logic electronics, drivers and wiring. | Pending |
| `dell_server_psu_label.jpg` | Dell server power-supply label. | Exact model, 12 V rating and current rating. | Pending |
| `lm2596s_converter.jpg` | DC-DC LM2596S module. | Input wiring, output wiring and module location. | Pending |
| `panic_button_wiring.jpg` | Panic-button or emergency cut-off wiring. | Evidence that actuator power is interrupted while logic remains powered. | Pending |
| `main_bus_wiring.jpg` | Main bus wiring. | 12V, P_GND, 5V, S_GND, CANH and CANL routing. | Pending |
| `can_termination_rt1.jpg` | CAN termination RT1. | 120-ohm resistor location at one end of CAN bus. | Pending |
| `can_termination_rt2.jpg` | CAN termination RT2. | 120-ohm resistor location at the other end of CAN bus. | Pending |
| `raspberry_pi_mcp2515.jpg` | Raspberry Pi 5 to MCP2515 wiring. | SPI, INT, power and CAN connection. | Pending |
| `j1_drv8871_node.jpg` | J1 controller node. | ESP32, DRV8871, encoder/motor/power/CAN connectors. | Pending |
| `j2_ibt2_node.jpg` | J2 controller node. | ESP32, IBT-2, encoder/motor/power/CAN connectors. | Pending |
| `j3_ibt2_node.jpg` | J3 controller node. | ESP32, IBT-2, encoder/motor/power/CAN connectors. | Pending |
| `j4_drv8871_gripper_node.jpg` | J4 controller node and gripper connection. | ESP32, DRV8871, servo/gripper wiring and connectors. | Pending |
| `j5_tb6600_node.jpg` | J5 elevator controller node. | ESP32, TB6600, PUL/DIR/ENA, power and CAN connectors. | Pending |

## Optional schematic captures

If PDF schematics are not easy to view in the final paper package, export or capture the following images:

| Image filename | Source schematic |
|---|---|
| `schematic_main_bus.png` | `electronics/schematics/Main Bus.pdf` |
| `schematic_raspberrypi_mcp2515.png` | `electronics/schematics/RASPBERRYPI_MCP2515.pdf` |
| `schematic_drv8871_node.png` | `electronics/schematics/DC_MOTOR_DRIVER_SCH.pdf` |
| `schematic_ibt2_node.png` | `electronics/schematics/DC_MOTOR_DRIVER_SCH_IBT2.pdf` |
| `schematic_stepper_j5_node.png` | `electronics/schematics/Stepper Driver v7.pdf` |

## Photo checklist

Before final HardwareX submission, each photo should have:

- clear focus;
- sufficient lighting;
- visible connector orientation;
- visible labels or annotations when needed;
- no personal or unrelated background information;
- consistent filename using lowercase words and underscores;
- corresponding reference from `electronics/wiring_diagrams/connector_table.md` when applicable.

## Information to record with each photo

For each photo, record the following in the commit message, file name or related documentation:

| Field | Example |
|---|---|
| Subsystem | J2 IBT-2 controller node |
| Related connector IDs | `C-IBT2-CTRL`, `C-IBT2-CAN`, `C-IBT2-PWR` |
| Signals visible | CANH, CANL, 12V, GND, encoder A/B |
| Verification result | Matches schematic / differs from schematic |
| Action required | Update connector table if mismatch is found |

## Related documents

- [`../wiring_diagrams/connector_table.md`](../wiring_diagrams/connector_table.md)
- [`../wiring_diagrams/nodos_controladores.md`](../wiring_diagrams/nodos_controladores.md)
- [`../power_distribution/power_summary.md`](../power_distribution/power_summary.md)
- [`../schematics/schematics_index.md`](../schematics/schematics_index.md)

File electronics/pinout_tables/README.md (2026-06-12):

# Tablas de pines

Colocar aqui tablas de asignacion de pines.

Tablas recomendadas:

- ESP32 a driver de motor
- ESP32 a modulo CAN
- Raspberry Pi a interfaz CAN
- pines del efector final
- notas de conexion de camara o sensores

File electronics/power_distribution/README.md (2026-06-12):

# Distribucion de potencia

Colocar aqui la documentacion de alimentacion electrica del sistema.

Archivos recomendados:

- diagrama de fuente de alimentacion
- tabla de lineas de voltaje
- notas de fusibles o protecciones
- notas de tierra o GND comun
- calibre de cables
- notas de paro de emergencia o desconexion

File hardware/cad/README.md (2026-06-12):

# CAD

Colocar aqui los archivos CAD editables del sistema mecanico.

Usar esta carpeta para los modelos fuente del robot completo, brazo, elevador, gripper y soportes. Los archivos exportados para revision deben ir en `hardware/step/` y los imprimibles en `hardware/stl/`.

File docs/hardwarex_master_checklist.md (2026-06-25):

# Checklist maestro HardwareX

Checklist maestro para preparar el repositorio como paquete reproducible.

Leyenda:

- `[x]` completado
- `[~]` parcial
- `[ ]` pendiente
- `[d]` diferido por falta de acceso físico al prototipo o por congelamiento final pendiente

## Índice

- [A. Identidad del hardware](#a-identidad-del-hardware)
- [B. Archivos mecánicos](#b-archivos-mecánicos)
- [C. Electrónica](#c-electrónica)
- [D. Firmware](#d-firmware)
- [E. ROS 2 y software](#e-ros-2-y-software)
- [F. Datos de validación](#f-datos-de-validación)
- [G. Manuscrito](#g-manuscrito)
- [H. Limpieza final](#h-limpieza-final)

## A. Identidad del hardware

- [x] Nombre de trabajo definido: Assistbelle / Robot asistivo 5-DOF.
- [x] Título tentativo del artículo definido.
- [x] Alcance limitado a laboratorio o entorno controlado.
- [ ] Nombre final del hardware confirmado.
- [ ] Resumen final del uso previsto.
- [ ] Limitaciones finales del prototipo declaradas.

## B. Archivos mecánicos

- [x] CAD completo del sistema elevador cargado: `hardware/cad/complete_robot/ASM_Elevator_System_v60.f3z`.
- [~] CAD completo del robot/brazo: fuera del cierre actual del paquete elevador v60 o pendiente de congelar según alcance final.
- [x] CAD del elevador cargado como snapshot de trabajo v60.
- [~] CAD del brazo: pendiente si el release final incluye brazo completo en este repositorio.
- [~] CAD del gripper: pendiente si el release final incluye gripper completo en este repositorio.
- [x] CAD de soportes y adaptadores principales del elevador incluido dentro del ensamblaje v60.
- [x] STEP completo cargado: `hardware/step/ASM_Elevator_System_v60.step`.
- [d] STEP por subconjunto: opcional para snapshot v60; agregar antes de congelar release final si se requiere mayor navegabilidad.
- [x] STL de piezas imprimibles/fabricadas cargado para las piezas identificadas en BOM v60.
- [x] Planos con dimensiones cargados para base plate, top plate y gantry plate.
- [x] DXF de fabricación cargado para top plate y gantry plate.
- [~] Tabla de tornillos, rodamientos, perfiles y piezas estándar documentada en BOM/fasteners; falta verificación física final.
- [d] Fotos del prototipo diferidas por falta de acceso físico al robot.

## C. Electrónica

- [x] Pinouts por nodo documentados.
- [x] Raspberry Pi a MCP2515 documentado.
- [x] Bus principal documentado parcialmente.
- [x] Driver por articulación documentado parcialmente.
- [x] Carpeta de esquemáticos creada.
- [x] Índice de esquemáticos creado.
- [ ] Confirmar que los esquemáticos cubren sistema general, CAN, potencia y drivers.
- [ ] Exportar esquemáticos a PDF/PNG si solo están en formato editable.
- [ ] Diagrama CAN final revisado.
- [ ] Diagrama de potencia final revisado.
- [ ] Tabla de conectores finales.
- [ ] Fotos o imágenes reales de electrónica.

## D. Firmware

- [x] Firmware migrado a `firmware/`.
- [x] Proyectos ESP-IDF J1-J4 agregados.
- [x] Proyecto ESP-IDF J5/TB6600 agregado.
- [x] Proyecto compilable localmente para J1-J5.
- [x] Instrucciones de carga documentadas.
- [x] IDs CAN documentados.
- [x] Parámetros de control documentados parcialmente.
- [ ] Límites de seguridad finales documentados.
- [ ] Confirmar formato final de payload CAN contra ROS 2.

## E. ROS 2 y software

- [x] Código ROS 2 mantenido dentro de `ros2_ws/`.
- [x] Guía de entry points creada.
- [x] Comandos SocketCAN documentados.
- [ ] Compilación reproducible validada desde clon limpio.
- [ ] Entry points verificados uno por uno.
- [ ] Dependencias Python verificadas.
- [ ] Script de visión definido claramente como nodo ROS o standalone.

## F. Datos de validación

- [x] Plan de validación creado.
- [x] Índice de media creado.
- [x] Tabla inicial J5 creada.
- [ ] Pruebas articulares curadas.
- [ ] Pruebas de cinemática curadas.
- [ ] Pruebas de percepción curadas.
- [ ] Pruebas pick-and-place curadas.
- [ ] Figuras finales listas.
- [ ] Videos o enlaces listos.
- [ ] Índice de dataset final listo.

## G. Manuscrito

- [ ] Tabla de especificaciones.
- [ ] Contexto del hardware.
- [ ] Descripción del hardware.
- [ ] Resumen de archivos de diseño.
- [ ] Resumen de lista de materiales.
- [ ] Instrucciones de construcción.
- [ ] Instrucciones de operación.
- [ ] Validación y caracterización.
- [ ] Notas de seguridad.
- [ ] Referencias.

## H. Limpieza final

- [x] `.gitignore` reforzado para ROS 2 y ESP-IDF.
- [x] `.gitattributes` configurado para Git LFS en CAD, STEP, STL, DXF y media pesada.
- [x] `LICENSE` creado.
- [x] `CITATION.cff` creado.
- [ ] Verificar que no queden artefactos versionados en `build`, `install`, `log`, `.vscode` o `.idea`.
- [ ] Reemplazar placeholders.
- [ ] Revisar enlaces internos.
- [ ] Revisar accesibilidad del repositorio.
- [ ] Eliminar o archivar checklists temporales.

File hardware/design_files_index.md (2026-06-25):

<!-- SPDX-License-Identifier: CC-BY-4.0 -->

# Mechanical design files index

This index tracks the mechanical design files currently available in the public repository.

The current uploaded CAD snapshot is **v60**. It is a working snapshot, not yet the final frozen HardwareX release. Future CAD snapshots should use their actual Fusion 360 version suffix, for example `_v61`, `_v62` or a final release tag when frozen.

## Complete assembly files

| File | Format | Subsystem | Status | Required for replication | Notes |
|---|---|---|---|---|---|
| [`cad/complete_robot/ASM_Elevator_System_v60.f3z`](cad/complete_robot/ASM_Elevator_System_v60.f3z) | Fusion 360 archive | Complete elevator assembly | Uploaded via Git LFS | Yes | Editable Fusion 360 package for the current v60 CAD snapshot. |
| [`step/ASM_Elevator_System_v60.step`](step/ASM_Elevator_System_v60.step) | STEP | Complete elevator assembly | Uploaded via Git LFS | Yes | Neutral CAD export for reviewers and users who do not use Fusion 360. |

## Pending subsystem STEP exports

Subsystem STEP exports are optional for the current working snapshot but recommended before the final HardwareX release.

| Target file | Status | Notes |
|---|---|---|
| `step/ASM_Elevator_Frame_v60.step` | Pending / optional | Fixed frame, base/top plates, V-slot profiles and structural brackets. |
| `step/ASM_Elevator_Carriage_v60.step` | Pending / optional | Moving carriage, gantry plates, spacers and V-wheel assemblies. |
| `step/ASM_Elevator_Drive_TR8_NEMA23_v60.step` | Pending / optional | NEMA23 motors, couplers, lead screws, nut blocks and supports. |
| `step/ASM_Elevator_Guide_VWheels_v60.step` | Pending / optional | Dual V-wheel guide path and wheel assemblies. |
| `step/ASM_Elevator_Electronics_Mounting_v60.step` | Pending / optional | Raspberry Pi, MCP2515 and TB6600 placement if electronics mounting is part of the CAD. |

## STL exports for fabricated/printed parts

| BOM ID | Target file | Status | Notes |
|---|---|---|---|
| `FAB_ACT_002` | [`stl/FAB_ACT_002_NEMA23_Mounting_Plate_ABS_v60.stl`](stl/FAB_ACT_002_NEMA23_Mounting_Plate_ABS_v60.stl) | Uploaded via Git LFS | NEMA 23 mounting plate STL for the current v60 snapshot. |
| `FAB_GUI_002` | [`stl/FAB_GUI_002_Spacer_Block_ABS_Gray_v60.stl`](stl/FAB_GUI_002_Spacer_Block_ABS_Gray_v60.stl) | Uploaded via Git LFS | Spacer block STL for the current v60 snapshot. |

## Drawings / fabrication files

| BOM ID | Target file | Status | Notes |
|---|---|---|---|
| `FAB_STR_001` | [`drawings/FAB_STR_001_Base_Plate_356x356x15_MDF_v60.pdf`](drawings/FAB_STR_001_Base_Plate_356x356x15_MDF_v60.pdf) | Uploaded | MDF base plate drawing with dimensions, material, units, tolerance and hole notes. |
| `FAB_STR_002` | [`drawings/FAB_STR_002_Top_Plate_420x400x3_StainlessSteel_v60.pdf`](drawings/FAB_STR_002_Top_Plate_420x400x3_StainlessSteel_v60.pdf) | Uploaded | Stainless steel top plate drawing with dimensions, material, units, tolerance and hole notes. |
| `FAB_GUI_001` | [`drawings/FAB_GUI_001_Gantry_Plate_127x88x3_StainlessSteel_v60.pdf`](drawings/FAB_GUI_001_Gantry_Plate_127x88x3_StainlessSteel_v60.pdf) | Uploaded | Stainless steel gantry plate drawing with dimensions, material, units, tolerance and hole notes. |
| `FAB_STR_002` | [`drawings/FAB_STR_002_Top_Plate_420x400x3_StainlessSteel_v60.dxf`](drawings/FAB_STR_002_Top_Plate_420x400x3_StainlessSteel_v60.dxf) | Uploaded via Git LFS | DXF for laser/waterjet cutting. Check scale before fabrication. |
| `FAB_GUI_001` | [`drawings/FAB_GUI_001_Gantry_Plate_127x88x3_StainlessSteel_v60.dxf`](drawings/FAB_GUI_001_Gantry_Plate_127x88x3_StainlessSteel_v60.dxf) | Uploaded via Git LFS | DXF for laser/waterjet cutting. Check scale before fabrication. |

## Deferred mechanical photos

Physical prototype photos are deferred because the robot is not currently available for imaging.

| Target file | Status | Notes |
|---|---|---|
| `photos/IMG_Elevator_Assembled_Front_v60.jpg` | Deferred / pending physical access | Overall front view. |
| `photos/IMG_Elevator_Assembled_Side_v60.jpg` | Deferred / pending physical access | Overall side view. |
| `photos/IMG_Elevator_Carriage_VWheels_v60.jpg` | Deferred / pending physical access | V-wheel guide evidence. |
| `photos/IMG_Elevator_TR8_NEMA23_Drive_v60.jpg` | Deferred / pending physical access | Lead screw, coupler and NEMA23 evidence. |
| `photos/IMG_Elevator_Top_Plate_v60.jpg` | Deferred / pending physical access | Top plate evidence. |
| `photos/IMG_Elevator_Base_Plate_v60.jpg` | Deferred / pending physical access | Base plate and structural bracket evidence. |

## Notes for HardwareX release

- The v60 files are a current working snapshot, not a final frozen release.
- Keep the complete `.f3z` and complete `.step` even if subsystem exports are later added.
- Do not upload individual STEP/STL files for every commercial screw, nut, bearing, motor or module unless required for reproduction.
- Physical prototype photos should be added once the robot is available again.
- Before final publication, make sure the final frozen CAD version matches the BOM snapshot or clearly document any version difference.

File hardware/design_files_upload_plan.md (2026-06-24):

<!-- SPDX-License-Identifier: CC-BY-4.0 -->

# Mechanical design files upload plan

This checklist defines the upload order, file names and target folders for the mechanical design package of the Assistbelle elevator subsystem.

Use this file to upload the HardwareX mechanical package step by step. The goal is to keep Fusion 360 editable files, neutral CAD exports, printable files, drawings and photos traceable to the BOM and CAD release.

The current uploaded CAD snapshot is **v60**. It is a working snapshot, not yet the final frozen HardwareX release.

## Large-file upload rule

Do **not** upload large CAD files through the GitHub browser uploader. GitHub browser uploads are limited to 25 MiB, and CAD packages such as `.f3z`, `.step` and `.stl` can easily exceed that. This repository includes `.gitattributes` so CAD, media and binary design files are tracked through Git LFS.

Recommended upload method for large CAD files:

```bash
git clone https://github.com/Yufagb/assistbelle-arm-elevator-subsystem.git
cd assistbelle-arm-elevator-subsystem
git lfs install
git pull

# Copy the file manually into the target folder, then:
git status
git add hardware/cad/complete_robot/ASM_Elevator_System_v60.f3z
git commit -m "Add Fusion 360 elevator assembly v60"
git push
```

If Git LFS is not available, use a GitHub Release asset or a stable Google Drive link as a temporary fallback, then document the link in `hardware/design_files_index.md`. Git LFS is preferred for reproducibility.

## General rules

- Use version suffix `_v60` for files derived from the current CAD working snapshot.
- Use clear English file names for public HardwareX readability.
- Keep purchased commercial parts in the CAD/STEP assembly, but do not export every screw/nut as an individual file unless needed for reproduction.
- Upload STL files only for fabricated/3D-printed parts.
- Upload drawings/PDF/DXF only for fabricated or cut parts.
- Keep photos in `hardware/photos/`, not mixed with CAD files.
- Keep electronics photos in `electronics/images/`, not in `hardware/photos/`.

## Step 1 — Editable Fusion 360 assembly

| Status | Source file to upload | Target path | Required? | Notes |
|---|---|---|---|---|
| [x] | `ASM_Elevator_System.f3z` | `hardware/cad/complete_robot/ASM_Elevator_System_v60.f3z` | Yes | Uploaded via Git LFS. Preferred editable assembly export because `.f3z` preserves referenced components. |
| [ ] | `ASM_Elevator_System.f3d` | `hardware/cad/complete_robot/ASM_Elevator_System_v60.f3d` | Optional | Upload only if it is a standalone Fusion design and does not depend on external references. Use Git LFS if large. |

## Step 2 — Full neutral CAD export

| Status | Source file to upload | Target path | Required? | Notes |
|---|---|---|---|---|
| [x] | `ASM_Elevator_System.step` | `hardware/step/ASM_Elevator_System_v60.step` | Yes | Uploaded via Git LFS. Main neutral CAD file for reviewers who do not use Fusion 360. |

## Step 3 — STEP exports by subsystem

Subsystem STEP exports are recommended before the final frozen HardwareX release, but they are optional for the current v60 working snapshot.

| Status | Source/export name | Target path | Required? | Notes |
|---|---|---|---|---|
| [ ] | Frame subsystem STEP | `hardware/step/ASM_Elevator_Frame_v60.step` | Recommended | V-slot frame, base/top plates and structural brackets. |
| [ ] | Carriage subsystem STEP | `hardware/step/ASM_Elevator_Carriage_v60.step` | Recommended | Moving carriage, gantry plates, spacers and V-wheel assemblies. |
| [ ] | Drive subsystem STEP | `hardware/step/ASM_Elevator_Drive_TR8_NEMA23_v60.step` | Recommended | NEMA23 motors, couplers, lead screws, nut blocks and supports. |
| [ ] | Guide subsystem STEP | `hardware/step/ASM_Elevator_Guide_VWheels_v60.step` | Recommended | Dual V-wheel guide path and wheel assemblies. |
| [ ] | Electronics mounting STEP | `hardware/step/ASM_Elevator_Electronics_Mounting_v60.step` | Optional | Raspberry Pi, MCP2515 and TB6600 placement if electronics mounting is part of the CAD. |

## Step 4 — STL files for 3D-printed/custom printed parts

| Status | BOM ID | Source/export name | Target path | Required? |
|---|---|---|---|---|
| [ ] | `FAB_ACT_002` | NEMA 23 mounting plate STL | `hardware/stl/FAB_ACT_002_NEMA23_Mounting_Plate_ABS_v60.stl` | Yes, if printed |
| [ ] | `FAB_GUI_002` | Spacer block STL | `hardware/stl/FAB_GUI_002_Spacer_Block_ABS_Gray_v60.stl` | Yes, if printed |
| [ ] | TBD | Any additional printed mount/bracket | `hardware/stl/<BOM_ID>_<Part_Name>_v60.stl` | If applicable |

Do not upload STL exports of purchased items such as V-slot profiles, NEMA23 motors, TB6600 drivers, Raspberry Pi, MCP2515 modules, screws, bearings or wheels unless the STL is needed as a visual placeholder only.

## Step 5 — Fabrication drawings and DXF files

| Status | BOM ID | Drawing/export name | Target path | Required? |
|---|---|---|---|---|
| [ ] | `FAB_STR_001` | MDF base plate drawing | `hardware/drawings/FAB_STR_001_Base_Plate_356x356x15_MDF_v60.pdf` | Yes |
| [ ] | `FAB_STR_002` | Stainless steel top plate drawing | `hardware/drawings/FAB_STR_002_Top_Plate_420x400x3_StainlessSteel_v60.pdf` | Yes |
| [ ] | `FAB_GUI_001` | Stainless steel gantry plate drawing | `hardware/drawings/FAB_GUI_001_Gantry_Plate_20x80_StainlessSteel_v60.pdf` | Yes |
| [ ] | `FAB_STR_002` | Top plate DXF | `hardware/drawings/FAB_STR_002_Top_Plate_420x400x3_StainlessSteel_v60.dxf` | Recommended if laser/waterjet cut |
| [ ] | `FAB_GUI_001` | Gantry plate DXF | `hardware/drawings/FAB_GUI_001_Gantry_Plate_20x80_StainlessSteel_v60.dxf` | Recommended if laser/waterjet cut |

## Step 6 — Mechanical photos

| Status | Photo to upload | Target path | Required? | Notes |
|---|---|---|---|---|
| [ ] | Full elevator front view | `hardware/photos/IMG_Elevator_Assembled_Front_v60.jpg` | Yes | Overall view for publication. |
| [ ] | Full elevator side view | `hardware/photos/IMG_Elevator_Assembled_Side_v60.jpg` | Yes | Shows depth, guide layout and frame. |
| [ ] | Carriage and V-wheel close-up | `hardware/photos/IMG_Elevator_Carriage_VWheels_v60.jpg` | Yes | Confirms Dual V-wheel guide implementation. |
| [ ] | TR8/NEMA23 drive close-up | `hardware/photos/IMG_Elevator_TR8_NEMA23_Drive_v60.jpg` | Yes | Confirms lead screw, coupler and motor placement. |
| [ ] | Top plate close-up | `hardware/photos/IMG_Elevator_Top_Plate_v60.jpg` | Recommended | Shows upper structure and supports. |
| [ ] | Base plate close-up | `hardware/photos/IMG_Elevator_Base_Plate_v60.jpg` | Recommended | Shows base structure, brackets and electronics placement if visible. |

## Step 7 — Electronics photos, stored separately

Electronics photos belong in `electronics/images/`.

| Status | Photo to upload | Target path | Required? |
|---|---|---|---|
| [ ] | Raspberry Pi + MCP2515 close-up | `electronics/images/IMG_RaspberryPi5_MCP2515_v60.jpg` | Yes |
| [ ] | TB6600 driver A close-up | `electronics/images/IMG_TB6600_Driver_J5_MotorA_v60.jpg` | Yes |
| [ ] | TB6600 driver B close-up | `electronics/images/IMG_TB6600_Driver_J5_MotorB_v60.jpg` | Yes |
| [ ] | Full electronics layout | `electronics/images/IMG_Electronics_Layout_v60.jpg` | Yes |
| [ ] | PSU label | `electronics/images/IMG_Dell_Server_PSU_Label_v60.jpg` | Recommended |

## Step 8 — Index update after upload

After files are uploaded, update or create:

- `hardware/design_files_index.md`
- `hardware/README.md`
- `docs/publication_checklist.md`
- `docs/hardwarex_master_checklist.md`

The design-files index should include file path, format, subsystem, BOM IDs, description and whether the file is required for replication.

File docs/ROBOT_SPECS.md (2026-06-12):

# Robot Specifications

## 🦾 Joint Limits

The robot consists of a prismatic base (J5/Ascensor) and a 4-DOF articulated arm (J1-J4).

| Joint | Type | Name | Min Limit | Max Limit | Unit |
| :--- | :--- | :--- | :--- | :--- | :--- |
| **J1** | Revolute | Base | -135° | +34° | Degrees |
| **J2** | Revolute | Shoulder | -45° | +70° | Degrees |
| **J3** | Revolute | Elbow | -140° | +120° | Degrees |
| **J4** | Revolute | Wrist | -180° | +180° | Degrees |
| **J5** | Prismatic | Elevator | 0 mm | 350 mm | Millimeters |

> **Note**: J5 is physically the base elevator, but is often addressed as index 5 or 0 in different contexts. In the CAN protocol, it is Motor 5.

## 📐 Denavit-Hartenberg (DH) Parameters

The kinematic chain is defined as follows:

| Link | $\theta$ (Offset) | $d$ (m) | $a$ (m) | $\alpha$ (rad) |
| :--- | :--- | :--- | :--- | :--- |
| **0 (Elevator)** | 0 | $d_0 + 0.4$ | 0 | 0 |
| **1 (Base)** | $\theta_1 + 360^\circ$ | 0 | 0 | -90° |
| **2 (Fixed)** | $180^\circ$ | 0.1 | 0 | 0 |
| **3 (Shoulder)** | $\theta_2 + 180^\circ$ | 0 | 0.215 | 0 |
| **4 (Elbow)** | $\theta_3$ | 0 | 0.25 | 180° |
| **5 (Wrist)** | $\theta_4$ | 0 | 0.125 | 90° |

## 🔌 Hardware Interface

*   **Bus**: CAN Bus (Controller Area Network)
*   **Bitrate**: 1 Mbps (typical)
*   **Interface**: `can0` (SocketCAN)
*   **Motors**: Custom actuators with integrated controllers.

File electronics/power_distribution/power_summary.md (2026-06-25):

<!-- SPDX-License-Identifier: CERN-OHL-S-2.0 -->

# Power distribution summary

This document summarizes the current power-distribution architecture for the Assistbelle robotic arm and elevator subsystem.

## Scope

The power system described here covers the arm and vertical elevator subsystem only. It does not describe the complete mobile base, autonomous navigation electronics, storage module or any clinical deployment configuration.

## Power architecture

| Rail / block | Nominal value | Function | Current status |
|---|---:|---|---|
| Main actuator supply | 12 V nominal | Power for actuators, motor drivers and high-current loads. | Final architecture uses a Dell server power supply; exact model pending. TB6600 supply voltage to be confirmed physically. |
| Main supply rating | 1 kW, 88 A, 12 V | Available high-current supply for actuator power bus. | Model to be specified. |
| Logic supply | 5 V, 5 A | Raspberry Pi, ESP32 nodes and low-power logic peripherals. | Generated with LM2596S DC-DC buck converter module. |
| DC-DC converter input | 24 V / 12 V input compatible | Step-down input range for the LM2596S module. | Used to generate the 5 V logic rail. |
| CAN bus | Differential CANH/CANL | Communication between Raspberry Pi/MCP2515 and ESP32 nodes. | Uses common reference through signal-side ground. |

## Grounding strategy

The implementation separates the high-current power ground and the signal-side ground:

| Ground line | Description | Notes |
|---|---|---|
| Power GND | Return path from the actuator supply. | Associated with motor drivers and actuator power. |
| Signal GND | Return/reference for the 5 V logic rail from the DC-DC converter. | Associated with Raspberry Pi, ESP32 nodes, CAN transceivers and telemetry. |

The power and signal grounds are intentionally documented as separate domains in the current architecture. Any final single-point bonding, isolation strategy or measurement reference should be verified and documented before publication.

## Emergency stop / panic button behavior

The user-confirmed design intent is that the panic button cuts actuator power while keeping the logic and telemetry electronics powered.

| Subsystem | Behavior when panic button is activated |
|---|---|
| Actuator power rail | Interrupted. Motor drivers and actuators stop receiving actuator-side power. |
| Raspberry Pi | Remains powered from the 5 V logic rail. |
| ESP32 nodes | Remain powered from the 5 V logic rail. |
| CAN/telemetry | Remains available for diagnostics and code testing. |
| J2 and J3 | Mechanically self-locking, so the arm does not lose position when actuator power is removed. |

This architecture allows safer intervention while preserving communication, telemetry and debugging capability.

## J5 elevator driver power note

The elevator uses two TB6600 drivers for two NEMA 23 motors. The user-confirmed control design sends the same `PUL`, `DIR` and `ENA` signals to both drivers in parallel. The supply voltage used by the two TB6600 drivers is still pending physical inspection and must be confirmed before final HardwareX submission.

## Removed power options

LiPo batteries are not part of the current public HardwareX package and should not be considered part of the active BOM or final reproducible configuration.

| Item | Status |
|---|---|
| LiPo battery pack | Removed from active design and BOM. |
| Battery-powered operation | Out of current public package scope. |

## Related components

| Component | Role | Status |
|---|---|---|
| Dell server power supply | 12 V, 1 kW, 88 A actuator supply. | Exact model pending. |
| LM2596S buck converter module | DC-DC 24 V / 12 V to 5 V, 5 A. | Used for logic rail. |
| Raspberry Pi 5 | Main computer / ROS 2 side. | Powered by logic rail. |
| ESP32 DevKitC nodes | Distributed control nodes. | Powered by logic rail. |
| MCP2515 CAN-SPI module | Raspberry Pi CAN interface. | Powered from 5 V by design; Raspberry Pi 3.3 V SPI/INT compatibility must be verified by module selection. |
| SN65HVD230 CAN transceivers | CAN physical layer. | Powered from logic side. |
| DRV8871 drivers | DC motor actuation. | Powered from actuator rail. |
| IBT-2 / BTS7960 drivers | J2/J3 DC motor actuation. | Powered from actuator rail; physical wiring to verify. |
| TB6600 drivers | J5/elevator stepper actuation. | Supply voltage pending physical inspection. |

## Publication notes

Before final HardwareX submission, the following information should be added or confirmed:

- exact Dell server power-supply model;
- supply voltage used by the two J5 TB6600 drivers;
- measured current draw of the actuator rail during representative tests;
- measured current draw of the 5 V logic rail;
- wiring diagram showing the panic-button cut-off path;
- final location of the LM2596S module;
- final ground-bonding or isolation strategy;
- photographs of the power supply, converter, panic button and wiring harness.

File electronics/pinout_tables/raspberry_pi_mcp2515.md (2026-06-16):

<!-- SPDX-License-Identifier: CERN-OHL-S-2.0 -->

# Raspberry Pi 5 to MCP2515

This document describes the Raspberry Pi 5 to MCP2515 CAN interface used in the Assistbelle robotic arm and elevator subsystem.

## Source

- Thesis / schematic reference: `RASPBERRYPI_MCP2515.pdf`.
- The reviewed schematic shows a Raspberry Pi 40-pin header, an MCP2515 10-pin header, a 2-pin CAN connector and a 2-pin power connector.

## Operating voltage note

The real implementation uses **5 V to power the MCP2515 module**.

The Raspberry Pi SPI and interrupt signals remain Raspberry Pi logic-level signals. Therefore, the MCP2515 module used in the final setup must be compatible with Raspberry Pi 3.3 V logic on the SPI/INT side, either through an appropriate module design, onboard level shifting or verified safe interface behavior.

## Pin mapping

| MCP2515 signal | Raspberry Pi BCM GPIO | Raspberry Pi physical pin | Notes |
|---|---:|---:|---|
| VCC / module power | - | 2 / 4 | 5 V supply for the MCP2515 module. |
| GND | - | 6 | Signal ground reference. |
| CS / CS_CAN | GPIO8 | 24 | SPI0 CE0, CAN interface chip select. |
| SCK | GPIO11 | 23 | SPI clock. |
| MOSI | GPIO10 | 19 | Data from Raspberry Pi to MCP2515. |
| MISO | GPIO9 | 21 | Data from MCP2515 to Raspberry Pi. |
| INT / INT_CAN | GPIO25 | 22 | MCP2515 interrupt line. |
| CANH | - | - | CAN high differential line. |
| CANL | - | - | CAN low differential line. |

## Schematic connector reference

| Connector | Pin count | Signals | Notes |
|---|---:|---|---|
| `J_RPI` | 40 | Raspberry Pi 40-pin GPIO header | Includes 3V3, 5V, GND, MOSI, MISO, SCK, CS_CAN and INT_CAN labels. |
| `J_MCP` | 10 | 3V3, GND, SCK, MOSI, MISO, CS_CAN, NC, INT_CAN, CANL, CANH | Header shown in the schematic for the MCP2515 module interface. |
| `J_CAN` | 2 | CANH, CANL | CAN bus connector. |
| `J_POWER` | 2 | 5V, GND | 5 V power connector used for the MCP2515 module supply in the real implementation. |

## Configuration used

```bash
dtparam=spi=on
dtoverlay=spi-bcm2835
dtoverlay=mcp2515-can0,oscillator=8000000,interrupt=25
```

## CAN startup

```bash
sudo ip link set can0 down 2>/dev/null || true
sudo ip link set can0 up type can bitrate 500000
ip -details link show can0
```

## Quick checks

```bash
ls /dev/spidev*
lsmod | grep -i spi
lsmod | grep -E 'mcp251x|can'
sudo modprobe mcp251x
sudo modprobe can_raw
sudo modprobe can_dev
ip link show
candump can0
```

## Electrical notes

- MCP2515 module supply in the current implementation: **5 V**.
- Raspberry Pi SPI/INT logic compatibility must be preserved at **3.3 V logic level**.
- Use 120-ohm CAN termination only at the physical ends of the CAN bus.
- All CAN nodes must use the same bitrate.
- The documented CAN bitrate is **500 kbit/s**.
- Confirm physically that CANH and CANL are not swapped.

## Physical verification checklist

- [ ] Photograph Raspberry Pi 5 to MCP2515 wiring.
- [ ] Confirm the MCP2515 module receives 5 V at its power input.
- [ ] Confirm the specific MCP2515 module used is safe for Raspberry Pi 3.3 V SPI/INT logic.
- [ ] Confirm `CS_CAN` is connected to GPIO8 / physical pin 24.
- [ ] Confirm `INT_CAN` is connected to GPIO25 / physical pin 22.
- [ ] Confirm CANH/CANL orientation at `J_CAN`.
- [ ] Update `electronics/images/README.md` with the final photo name when uploaded.

## Related documents

- [`../schematics/RASPBERRYPI_MCP2515.pdf`](../schematics/RASPBERRYPI_MCP2515.pdf)
- [`../schematics/schematics_index.md`](../schematics/schematics_index.md)
- [`../wiring_diagrams/connector_table.md`](../wiring_diagrams/connector_table.md)
- [`../wiring_diagrams/bus_principal.md`](../wiring_diagrams/bus_principal.md)

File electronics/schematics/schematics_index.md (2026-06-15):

<!-- SPDX-License-Identifier: CERN-OHL-S-2.0 -->

# Schematics index

This document indexes the schematic PDFs for the Assistbelle robotic arm and elevator subsystem and records the electrical information extracted from each sheet.

## Schematic files

| File | Subsystem | Main blocks shown | Status |
|---|---|---|---|
| `DC_MOTOR_DRIVER_SCH.pdf` | DRV8871 DC motor controller node | ESP32 NodeMCU, SN65HVD230DR CAN transceiver, DRV8871DDA, power/CAN/motor headers. | Reviewed from uploaded PDF; physical wiring still pending. |
| `DC_MOTOR_DRIVER_SCH_IBT2.pdf` | IBT-2 DC motor controller node | ESP32 NodeMCU, SN65HVD230DR CAN transceiver, IBT-2 connector, power/CAN/motor headers. | Reviewed from uploaded PDF; physical wiring still pending. |
| `Main Bus.pdf` | Main power and CAN bus | 12 V, P_GND, 5 V, S_GND, CANH, CANL, RT1/RT2 120-ohm terminations and subsystem connectors. | Reviewed from uploaded PDF; physical implementation still pending. |
| `RASPBERRYPI_MCP2515.pdf` | Raspberry Pi to MCP2515 interface | Raspberry Pi 40-pin header, MCP2515 10-pin header, CAN connector and power connector. | Reviewed from uploaded PDF; module supply voltage must be verified. |
| `Stepper Driver v7.pdf` | J5 stepper/elevator controller | ESP32 NodeMCU, CAN transceiver, J_CAN, J_DRIVERS and J_5V connectors. | Reviewed from uploaded PDF; physical wiring still pending. |

## Extracted connector summary

| Schematic | Connector | Pin count | Signals / function | Notes |
|---|---|---:|---|---|
| `Main Bus.pdf` | `12V_PSU` | 2 | 12V, P_GND | Main actuator supply input. |
| `Main Bus.pdf` | `5V_PSU` | 2 | 5V, S_GND | Logic supply input. |
| `Main Bus.pdf` | `MCP_2515` | 2 | CANH, CANL | CAN branch for MCP2515. |
| `Main Bus.pdf` | `RPI_POWER` | 2 | 5V, S_GND | Raspberry Pi power branch. |
| `Main Bus.pdf` | `DCM_MOTOR_POWER` | 2 | 12V, P_GND | DC motor controller actuator power branch; used for four DC motor controllers. |
| `Main Bus.pdf` | `DCM_LOGIC_POWER` | 2 | 5V, S_GND | DC motor controller logic power branch. |
| `Main Bus.pdf` | `DCM_CAN_SN65H` | 2 | CANH, CANL | CAN branch for DC motor controller transceiver. |
| `Main Bus.pdf` | `STPR_LOGIC_POWER` | 2 | 5V, S_GND | Stepper/elevator logic power branch. |
| `Main Bus.pdf` | `STPR_CAN_SN65H` | 2 | CANH, CANL | CAN branch for stepper/elevator transceiver. |
| `DC_MOTOR_DRIVER_SCH.pdf` | `POWER_HEADERS` | 2 | 12V, GND | DRV8871 motor power. |
| `DC_MOTOR_DRIVER_SCH.pdf` | `J2` | 2 | 5V, GND | Logic power. |
| `DC_MOTOR_DRIVER_SCH.pdf` | `CAN_HEADER` | 2 | CANH, CANL | CAN bus connector. |
| `DC_MOTOR_DRIVER_SCH.pdf` | `MOTOR_HEADER` | 6 | M1, M2, 3V3, GND, ENCODER_A, ENCODER_B | Motor and encoder header. |
| `DC_MOTOR_DRIVER_SCH_IBT2.pdf` | `POWER_HEADERS` | 2 | 12V, GND | Board-level motor power header. |
| `DC_MOTOR_DRIVER_SCH_IBT2.pdf` | `J2` | 2 | 5V, GND | Logic power. |
| `DC_MOTOR_DRIVER_SCH_IBT2.pdf` | `CAN_HEADER` | 2 | CANH, CANL | CAN bus connector. |
| `DC_MOTOR_DRIVER_SCH_IBT2.pdf` | `MOTOR_HEADER` | 6 | M1, M2, 3V3, GND, ENCODER_A, ENCODER_B | Motor and encoder header. |
| `DC_MOTOR_DRIVER_SCH_IBT2.pdf` | `IBT2_CONN` | 8 | IN1, IN2, 5V, GND and IBT-2 control/interface pins | Exact pin order must be checked physically. |
| `DC_MOTOR_DRIVER_SCH_IBT2.pdf` | `IBT_POWER_HEADER` | 2 | 12V, GND | IBT-2 power branch. |
| `DC_MOTOR_DRIVER_SCH_IBT2.pdf` | `IBT_MOTOR_HEADER` | 2 | M1, M2 | Motor output branch. |
| `RASPBERRYPI_MCP2515.pdf` | `J_RPI` | 40 | Raspberry Pi GPIO header | Uses SPI and interrupt signals. |
| `RASPBERRYPI_MCP2515.pdf` | `J_MCP` | 10 | 3V3, GND, SCK, MOSI, MISO, CS_CAN, NC, INT_CAN, CANL, CANH | MCP2515-side header. |
| `RASPBERRYPI_MCP2515.pdf` | `J_CAN` | 2 | CANH, CANL | CAN bus connector. |
| `RASPBERRYPI_MCP2515.pdf` | `J_POWER` | 2 | 5V, GND | Power connector. |
| `Stepper Driver v7.pdf` | `J_CAN` | 2 | CANH, CANL | CAN bus connector. |
| `Stepper Driver v7.pdf` | `J_DRIVERS` | 3 | ENA, DIR, PUL | TB6600/elevator driver control. |
| `Stepper Driver v7.pdf` | `J_5V` | 2 | 5V, GND | Logic power connector. |

## Extracted component summary

| Schematic | Components identified |
|---|---|
| `DC_MOTOR_DRIVER_SCH.pdf` | ESP32 NodeMCU, SN65HVD230DR, DRV8871DDA, R1 20k on ILIM path. |
| `DC_MOTOR_DRIVER_SCH_IBT2.pdf` | ESP32 NodeMCU, SN65HVD230DR, IBT-2 interface connector. |
| `Main Bus.pdf` | Main six-line bus: 12V, P_GND, 5V, S_GND, CANH, CANL; two 120-ohm terminations RT1 and RT2. |
| `RASPBERRYPI_MCP2515.pdf` | Raspberry Pi 40-pin header, MCP2515 10-pin header, CAN connector and power connector. |
| `Stepper Driver v7.pdf` | ESP32 NodeMCU, CAN transceiver, J_CAN, J_DRIVERS and J_5V connectors. |

## Important verification notes

- `Main Bus.pdf` shows RT1 and RT2 as 120-ohm CAN terminations between CANH and CANL.
- `RASPBERRYPI_MCP2515.pdf` shows the MCP header using `3V3`, while a separate `J_POWER` connector provides `5V` and `GND`; the actual MCP2515 module voltage must be verified on the robot.
- `Stepper Driver v7.pdf` shows J5/elevator control signals `PUL`, `DIR` and `ENA`, and the visible ESP32 mapping is consistent with `PUL GPIO5`, `DIR GPIO18`, `ENA GPIO19`, `CAN_RX GPIO21`, and `CAN_TX GPIO22`.
- `DC_MOTOR_DRIVER_SCH.pdf` and `DC_MOTOR_DRIVER_SCH_IBT2.pdf` are generic controller-node schematics; final assignment to J1-J4 must be verified against the physical robot.

## Physical review checklist

- [ ] Confirm that the GitHub `electronics/schematics/` folder contains the same five PDFs listed above.
- [ ] Confirm if schematic PDFs are final exports or if editable KiCad/source files also exist.
- [ ] Confirm MCP2515 module voltage: 3.3 V or 5 V.
- [ ] Confirm CAN termination resistor locations RT1 and RT2 on the real wiring.
- [ ] Confirm connector pin order for all 2-pin, 3-pin, 6-pin, 8-pin and 10-pin connectors.
- [ ] Photograph each connector and driver board.
- [ ] Update `electronics/wiring_diagrams/connector_table.md` with final connector models, pin numbers, wire colors and cable gauges.

## Related documents

- [`../README.md`](../README.md)
- [`../pinout_tables/esp32_pinout_table.md`](../pinout_tables/esp32_pinout_table.md)
- [`../pinout_tables/raspberry_pi_mcp2515.md`](../pinout_tables/raspberry_pi_mcp2515.md)
- [`../wiring_diagrams/bus_principal.md`](../wiring_diagrams/bus_principal.md)
- [`../wiring_diagrams/connector_table.md`](../wiring_diagrams/connector_table.md)
- [`../power_distribution/power_summary.md`](../power_distribution/power_summary.md)

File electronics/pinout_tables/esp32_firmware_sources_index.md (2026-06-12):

# Indice de fuentes para completar pinout ESP32

Este archivo relaciona las carpetas de Drive con las carpetas del repositorio para completar las tablas de pines.

## Fuentes revisadas

| Drive | Contenido | Destino en GitHub |
|---|---|---|
| JointVelocityControllers/J1 | Proyecto ESP-IDF de articulacion J1 | firmware/esp32_joint_node/J1 |
| JointVelocityControllers/J2 | Proyecto ESP-IDF de articulacion J2 | firmware/esp32_joint_node/J2 |
| JointVelocityControllers/J3 | Proyecto ESP-IDF de articulacion J3 | firmware/esp32_joint_node/J3 |
| JointVelocityControllers/J4 | Proyecto ESP-IDF de articulacion J4 y gripper | firmware/esp32_joint_node/J4 |
| JointPositionControllers/twai_id_based_basedness | Prueba o base de comunicacion TWAI/CAN | firmware/esp32_stepper_node/J5 o firmware/can_protocol |
| JointPositionControllers/codigo para diferentes nodos | Archivos nodo1.c a nodo4.c | revisar antes de migrar |

## Archivos clave a revisar

Para cada J1-J4:

- `main/node_config.h`: IDs de nodo, configuracion de articulacion y posiblemente pines.
- `main/motor_driver.h`: pines de driver DC.
- `main/encoder_driver.h`: pines del encoder.
- `main/twai_comms.h`: pines TWAI/CAN y bitrate.
- `main/grip_controller.h`: pines del gripper en J4, si aplica.

Para J5/elevador:

- archivo principal `.c` del proyecto final usado.
- definiciones STEP/DIR/EN.
- definiciones de TWAI/CAN.

## Tabla pendiente de completar

| Nodo | Archivo fuente esperado | Pines que faltan |
|---|---|---|
| J1 | node_config.h, motor_driver.h, encoder_driver.h, twai_comms.h | CAN TX/RX, PWM/DIR, encoder A/B. |
| J2 | node_config.h, motor_driver.h, encoder_driver.h, twai_comms.h | CAN TX/RX, RPWM/LPWM/R_EN/L_EN, encoder A/B. |
| J3 | node_config.h, motor_driver.h, encoder_driver.h, twai_comms.h | CAN TX/RX, RPWM/LPWM/R_EN/L_EN, encoder A/B. |
| J4 | node_config.h, motor_driver.h, encoder_driver.h, grip_controller.h, twai_comms.h | CAN TX/RX, motor DC, encoder A/B, servo PWM. |
| J5 | archivo final del elevador | CAN TX/RX, STEP, DIR, EN para motores PaP. |

## Nota

El conector permitio listar y ubicar los archivos de Drive, pero no devolvio el contenido textual de los `.c` y `.h`. Por eso queda preparada la estructura y la relacion de archivos, pero la extraccion exacta de pines debe hacerse copiando los archivos fuente a GitHub o compartiendolos como ZIP/archivo adjunto en el chat.

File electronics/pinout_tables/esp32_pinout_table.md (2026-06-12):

# Tabla de pines ESP32

Documento generado a partir de los ZIP subidos al chat:

- `JointPosition y JointVelocity Controllers.zip`
- `can-controll-.zip`

Los pines fueron extraidos principalmente de `node_config.h` para J1-J4 y de `twai_network_example_slave_main.c` para J5/elevador.

## Resumen por nodo

| Nodo | Subsistema | Driver | CAN TX | CAN RX | Motor IN1 / STEP | Motor IN2 / DIR | ENA | Encoder A | Encoder B | Gripper |
|---|---|---|---:|---:|---:|---:|---:|---:|---:|---:|
| J1 | Base | DRV8871 | GPIO21 | GPIO22 | GPIO32 | GPIO33 | - | GPIO10 | GPIO13 | No |
| J2 | Hombro | DRV8871 / etapa DC | GPIO22 | GPIO21 | GPIO5 | GPIO17 | - | GPIO19 | GPIO18 | No |
| J3 | Codo | DRV8871 / etapa DC | GPIO21 | GPIO22 | GPIO32 | GPIO33 | - | GPIO10 | GPIO13 | No |
| J4 | Muneca + gripper | DRV8871 / etapa DC + servo | GPIO33 | GPIO32 | GPIO25 | GPIO26 | - | GPIO2 | GPIO15 | GPIO4 |
| J5 | Elevador prismático | TB6600 | GPIO22 | GPIO21 | PUL GPIO5 | DIR GPIO18 | GPIO19 | - | - | No |

## J1 - Base

Fuente: `JointVelocityControllers/J1/main/node_config.h`.

| Funcion | GPIO ESP32 | Definicion en firmware |
|---|---:|---|
| CAN TX | GPIO21 | `TX_GPIO_NUM` |
| CAN RX | GPIO22 | `RX_GPIO_NUM` |
| Driver IN1 | GPIO32 | `DRV_IN1` |
| Driver IN2 | GPIO33 | `DRV_IN2` |
| Encoder A | GPIO10 | `ENCODER_A_PIN` |
| Encoder B | GPIO13 | `ENCODER_B_PIN` |
| ILIM | Interno por DAC | `ILIM_CONNECTED`, `DAC_CHAN_0` |

IDs CAN:

| Mensaje | ID |
|---|---:|
| Solicitud de estado | `0x0A1` |
| Respuesta de estado | `0x0B1` |
| Cambio de setpoint | `0x0C1` |
| Modo de control | `0x0D1` |
| Broadcast estado | `0x0A6` |

## J2 - Hombro

Fuente: `JointVelocityControllers/J2/main/node_config.h`.

| Funcion | GPIO ESP32 | Definicion en firmware |
|---|---:|---|
| CAN TX | GPIO22 | `TX_GPIO_NUM` |
| CAN RX | GPIO21 | `RX_GPIO_NUM` |
| Driver IN1 | GPIO5 | `DRV_IN1` |
| Driver IN2 | GPIO17 | `DRV_IN2` |
| Encoder A | GPIO19 | `ENCODER_A_PIN` |
| Encoder B | GPIO18 | `ENCODER_B_PIN` |
| ILIM | Interno por DAC | `ILIM_CONNECTED`, `DAC_CHAN_0` |

IDs CAN:

| Mensaje | ID |
|---|---:|
| Solicitud de estado | `0x0A2` |
| Respuesta de estado | `0x0B2` |
| Cambio de setpoint | `0x0C2` |
| Modo de control | `0x0D1` |
| Broadcast estado | `0x0A6` |

## J3 - Codo

Fuente: `JointVelocityControllers/J3/main/node_config.h`.

| Funcion | GPIO ESP32 | Definicion en firmware |
|---|---:|---|
| CAN TX | GPIO21 | `TX_GPIO_NUM` |
| CAN RX | GPIO22 | `RX_GPIO_NUM` |
| Driver IN1 | GPIO32 | `DRV_IN1` |
| Driver IN2 | GPIO33 | `DRV_IN2` |
| Encoder A | GPIO10 | `ENCODER_A_PIN` |
| Encoder B | GPIO13 | `ENCODER_B_PIN` |
| ILIM | Interno por DAC | `ILIM_CONNECTED`, `DAC_CHAN_0` |

IDs CAN:

| Mensaje | ID |
|---|---:|
| Solicitud de estado | `0x0A3` |
| Respuesta de estado | `0x0B3` |
| Cambio de setpoint | `0x0C3` |
| Modo de control | `0x0D1` |
| Broadcast estado | `0x0A6` |

## J4 - Muneca y gripper

Fuente: `JointVelocityControllers/J4/main/node_config.h`.

| Funcion | GPIO ESP32 | Definicion en firmware |
|---|---:|---|
| CAN TX | GPIO33 | `TX_GPIO_NUM` |
| CAN RX | GPIO32 | `RX_GPIO_NUM` |
| Driver IN1 | GPIO25 | `DRV_IN1` |
| Driver IN2 | GPIO26 | `DRV_IN2` |
| Encoder A | GPIO2 | `ENCODER_A_PIN` |
| Encoder B | GPIO15 | `ENCODER_B_PIN` |
| Servo gripper | GPIO4 | `GRIPPER_PIN` |

IDs CAN:

| Mensaje | ID |
|---|---:|
| Solicitud de estado | `0x0A4` |
| Respuesta de estado | `0x0B4` |
| Cambio de setpoint | `0x0C4` |
| Modo de control | `0x0D1` |
| Comando gripper | `0x0D2` |
| Broadcast estado | `0x0A6` |

## J5 - Elevador / motores NEMA 23

Fuente: `can-controll-/main/twai_network_example_slave_main.c`.

| Funcion | GPIO ESP32 | Definicion en firmware |
|---|---:|---|
| CAN TX | GPIO22 | `CAN_TX_GPIO` |
| CAN RX | GPIO21 | `CAN_RX_GPIO` |
| TB6600 ENA | GPIO19 | `ENA_PIN` |
| TB6600 DIR | GPIO18 | `DIR_PIN` |
| TB6600 PUL | GPIO5 | `PUL_PIN` |

IDs CAN:

| Mensaje | ID |
|---|---:|
| Solicitud de posicion J5 | `0x0A5` / `0xA5` |
| Broadcast solicitud | `0x0A6` / `0xA6` |
| Respuesta posicion J5 | `0x0B5` / `0xB5` |
| Comando posicion J5 | `0x0C5` / `0xC5` |

## Parametros relevantes

| Nodo | PPR encoder | Reduccion | Filtro velocidad | Frecuencia control |
|---|---:|---:|---:|---:|
| J1 | 68 | 131 | 0.01 | 500 Hz |
| J2 | 68 | 19*50 | 0.01 | 500 Hz |
| J3 | 64 | 1000*1.0125 | 0.01 | 500 Hz |
| J4 | 64 | 131 | 0.25 | 500 Hz |
| J5 | - | tornillo T8, lead 8 mm | - | 500 pulsos/s |

## Observaciones

- J1, J2 y J3 tienen `ILIM_CONNECTED`; J4 no.
- J4 define `NODE_HAS_GRIPPER` y usa `GRIPPER_PIN GPIO4`.
- J5 usa TB6600 con `ENA=GPIO19`, `DIR=GPIO18`, `PUL=GPIO5`.
- La comunicacion CAN/TWAI trabaja a 500 kbit/s.
- Algunos comentarios internos de los archivos indican nombres de nodos distintos; para documentacion se toma como referencia el nombre de la carpeta J1-J4 y los IDs CAN definidos.

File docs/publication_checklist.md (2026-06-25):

<!-- SPDX-License-Identifier: CC-BY-4.0 -->

# Publication checklist for HardwareX

This checklist replaces the previous temporary checklist. It tracks the remaining work for submitting `assistbelle-arm-elevator-subsystem` as a public HardwareX-style open-source hardware package.

Legend:

- `[x]` done
- `[~]` partial
- `[ ]` pending
- `[d]` deferred / blocked by unavailable physical prototype or final release freeze

## 1. Repository organization

- [x] Public repository created: `Yufagb/assistbelle-arm-elevator-subsystem`.
- [x] Main branch selected for publication: `main`.
- [x] Root README reorganized for HardwareX.
- [x] Folder structure created: `docs/`, `electronics/`, `firmware/`, `hardware/`, `paper/`, `ros2_ws/`, `software/`, `validation/`.
- [x] `.gitignore` reinforced for ROS 2, Python, ESP-IDF, build folders and IDE folders.
- [x] Git LFS configured for large CAD, STEP, STL, DXF and media assets.
- [x] Confirm there are no tracked generated files: local `git ls-files` validation found no tracked generated/local-state files.

## 2. Licensing and citation

- [x] Root `LICENSE` file converted into a multi-license overview.
- [x] `LICENSES/Apache-2.0.txt` added for software, firmware and scripts.
- [x] `LICENSES/CERN-OHL-S-2.0.txt` added for hardware design files.
- [x] `LICENSES/CC-BY-4.0.txt` added for documentation and paper assets.
- [x] `CITATION.cff` added and updated to the public repository URL.
- [x] `docs/license_overview.md` updated with the license policy.
- [~] SPDX policy documented. Add file-level SPDX comments progressively when touching files.

## 3. Mechanical hardware

- [x] Upload editable CAD files: `hardware/cad/complete_robot/ASM_Elevator_System_v60.f3z`.
- [x] Upload full STEP export: `hardware/step/ASM_Elevator_System_v60.step`.
- [x] Upload STL exports for printable/fabricated parts currently identified in the elevator BOM.
- [x] Upload drawings with dimensions for fabricated plates.
- [x] Upload DXF fabrication files for stainless-steel cut plates.
- [~] Complete fasteners table: screws, nuts, bearings, profiles and standard parts are represented in BOM/fastener docs; final physical cross-check remains pending.
- [x] Confirm mechanical files are covered by CERN-OHL-S v2.0 through repository license policy.
- [d] Add photos of the assembled elevator/mechanical subsystem once the physical robot is accessible again.
- [d] STEP exports by subsystem are optional for the current v60 working snapshot and can be added before final release freeze.

## 4. Electronics

- [x] Pinout table for ESP32 nodes documented.
- [x] Raspberry Pi + MCP2515 documented.
- [x] Main CAN/power bus documented in text.
- [x] Schematics folder and index created.
- [~] Connector table updated with confirmed design intent; exact pin order, wire colors and connector models remain pending physical inspection.
- [~] Power summary updated with emergency-stop behavior and J5 dual-TB6600 notes; TB6600 supply voltage remains pending physical inspection.
- [ ] Confirm final schematic file names.
- [~] Add final CAN diagram: Mermaid draft created in `paper/figures/electronics_can_architecture_mermaid.md`; final vector export pending.
- [~] Add final power-distribution diagram: Mermaid draft created in `paper/figures/power_distribution_mermaid.md`; final vector export pending.
- [ ] Add electronics photos.
- [ ] Confirm electronics design files are covered by CERN-OHL-S v2.0.

## 5. Firmware

- [x] ESP32 firmware migrated to `firmware/`.
- [x] Firmware separated by node J1-J5.
- [x] ESP-IDF build guide added.
- [x] CAN IDs documented.
- [x] J5/TB6600 firmware included.
- [~] CAN payloads reviewed against ROS 2. `C5` is compatible; `B5` needs final decision because ROS expects position+velocity and current firmware returns position+reserved/status bytes.
- [ ] Document final safety limits in firmware.
- [ ] Decide final `B5` format and update firmware or ROS 2 accordingly.
- [ ] Add SPDX comments to source files when editing them.

## 6. ROS 2 software

- [x] Workspace kept in `ros2_ws/`.
- [x] `can_comm_pkg` included.
- [x] `can_node` validated with virtual CAN.
- [x] Main entry points documented.
- [~] J5 ROS/CAN compatibility documented; `C5` uses mm as `float32` little-endian.
- [ ] Validate all entry points one by one from a clean clone.
- [ ] Clarify whether product-identification scripts are ROS nodes or standalone helpers.
- [ ] Verify Python dependencies and system dependencies.
- [ ] Add SPDX comments to source files when editing them.

## 7. BOM

- [x] Clean HardwareX elevator BOM exported to `docs/bom/hardwarex_elevator_bom_final.csv`.
- [x] Human-readable BOM summary created at `docs/bom/hardwarex_elevator_bom_final.md`.
- [x] BOM synchronized with the current CAD/BOM review: 32 item rows + one estimated-total row.
- [x] Current estimated product/material total documented: USD 484.78.
- [x] Removed unused/legacy components from the active BOM scope: Astra/Astra Plus, LiPo, tablet and DRV8825.
- [x] DRV8871, IBT-2/BTS7960 and TB6600 differentiated in procurement and electronics documentation.
- [x] `FAB_GUI_001` updated to `Gantry plate, 127 x 88 x 3 mm` based on v60 CAD/drawing.
- [~] Separate installed components from tools/lab equipment if required by HardwareX.
- [~] Confirm final suppliers and alternatives; Raspberry Pi 5 exact seller/product remains pending.
- [~] Confirm final quantities after final CAD/mechanical freeze.

## 8. Manuals

- [x] Operation manual created.
- [x] Troubleshooting guide created.
- [x] Safety notes created.
- [~] Calibration manual created but still basic.
- [ ] Expand calibration with offsets, limits and direction checks.
- [ ] Expand safety notes with formal risk categories and pre-operation checklist.
- [ ] Add assembly instructions after CAD/mechanical closure.

## 9. Validation

- [x] Validation structure created.
- [x] Validation plan created.
- [x] Media index created.
- [x] Initial J5 motion summary created.
- [~] Curate videos into `validation/media/` or provide stable external links: full video set remains local and uncommitted due size; representative subset still pending.
- [x] Curate final CSV/TXT data files: J1-J5 motion data and Tracker text exports uploaded in `validation/joint_motion_tests/raw/`.
- [~] Generate final validation figures from curated CSVs: plots and Tracker figures uploaded; manuscript-ready summary figures still pending.
- [ ] Document physical CAN validation.
- [ ] Document pick-and-place validation.
- [~] Document perception validation: perception figures uploaded; final narrative/video evidence still pending.

## 10. Manuscript material

- [x] Create manuscript draft or outline: `paper/manuscript_outline.md`.
- [~] Add final architecture figure: Mermaid draft created in `paper/figures/system_architecture_mermaid.md`; final vector export pending.
- [~] Add final electronics figure: Mermaid draft created in `paper/figures/electronics_can_architecture_mermaid.md`; final vector export pending.
- [~] Add final mechanical figure: figure plan created in `paper/figures/mechanical_figure_plan.md`; CAD render/photo export pending.
- [ ] Add validation figures and tables.
- [x] Add design-files summary table: `paper/tables/design_files_summary.md`.
- [x] Add BOM summary table: `paper/tables/bom_summary.md`.
- [x] Add data availability statement: `paper/data_availability_statement.md`.
- [ ] Add references.

## 11. Final cleanup

- [x] Replace remaining obvious publication placeholders: local grep validation found no obvious metadata/publication placeholders outside `docs/repo_cleanup_audit.md`.
- [~] Check all links in root README and docs README: main README files were refreshed for v60/BOM status; full automated Markdown link check still pending.
- [ ] Confirm public access to repository.
- [ ] Confirm license policy is reflected in README, LICENSE and docs/license_overview.md.
- [ ] Run a clean-clone reproducibility test.
- [ ] Archive or remove obsolete temporary notes after final submission.

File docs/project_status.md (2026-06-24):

# Estado actual del proyecto HardwareX

Este documento resume el estado real del repositorio público `assistbelle-arm-elevator-subsystem`.

## Índice

- [Resumen ejecutivo](#resumen-ejecutivo)
- [Estado por área](#estado-por-área)
- [BOM activa](#bom-activa)
- [Pendientes inmediatos](#pendientes-inmediatos)
- [Criterio de cierre para HardwareX](#criterio-de-cierre-para-hardwarex)

## Resumen ejecutivo

El repositorio ya tiene una estructura ordenada para publicación tipo HardwareX. Se separan correctamente ROS 2, firmware ESP32, electrónica, hardware mecánico, validación, documentación y material del paper.

El firmware ESP32 J1-J5 compila localmente. ROS 2 compila localmente para `can_comm_pkg`, y `can_node` inicia con una interfaz `can0` virtual usando SocketCAN/vcan.

La BOM HardwareX del elevador fue sincronizada con el Google Sheet `ASM_Elevator_System_HardwareX_BOM`, pestaña `BOM_Final_Clean`, asociada al CAD v54. Incluye estructura, actuación, guías, fasteners y electrónica CAD: Raspberry Pi 5, MCP2515 CAN-SPI y dos drivers TB6600. La BOM anterior `docs/bom_template.csv` se conserva como referencia histórica/continuidad, pero la BOM limpia para publicación del elevador está en `docs/bom/hardwarex_elevator_bom_final.csv`.

## Estado por área

| Área | Estado | Observación |
|---|---|---|
| Estructura del repo | Avanzada | Ver [`repository_structure.md`](repository_structure.md). |
| README principal | Avanzado | Con navegación interna, BOM v54 sincronizada y enlaces funcionales. |
| Firmware J1-J4 | Compila localmente | [`../firmware/esp32_joint_node/`](../firmware/esp32_joint_node/) |
| Firmware J5 | Compila localmente | [`../firmware/esp32_stepper_node/J5_tb6600/`](../firmware/esp32_stepper_node/J5_tb6600/) |
| Pinout ESP32 | Documentado | [`../electronics/pinout_tables/esp32_pinout_table.md`](../electronics/pinout_tables/esp32_pinout_table.md) |
| Raspberry Pi/MCP2515 | Documentado e incluido en BOM/CAD | [`../electronics/pinout_tables/raspberry_pi_mcp2515.md`](../electronics/pinout_tables/raspberry_pi_mcp2515.md), [`bom/hardwarex_elevator_bom_final.md`](bom/hardwarex_elevator_bom_final.md) |
| Bus principal | Documentado en texto | [`../electronics/wiring_diagrams/bus_principal.md`](../electronics/wiring_diagrams/bus_principal.md) |
| Esquemáticos | En proceso de cierre | [`../electronics/schematics/schematics_index.md`](../electronics/schematics/schematics_index.md) |
| Protocolo CAN | Documentado | [`../firmware/can_protocol/can_messages.md`](../firmware/can_protocol/can_messages.md) |
| ROS 2 | Compila e inicia con vcan | Falta probar todos los entry points. |
| BOM | Sincronizada con Google Sheet / CAD v54 | [`bom/hardwarex_elevator_bom_final.md`](bom/hardwarex_elevator_bom_final.md), 32 ítems + total estimado. |
| Licencia/citación | Inicial listo | [`../LICENSE`](../LICENSE), [`../CITATION.cff`](../CITATION.cff) |
| CAD/STEP/STL | Pendiente crítico | Falta contenido mecánico final. |
| Validación | Estructura lista | Falta copiar/enlazar evidencias. |
| Paper | Pendiente | Carpeta creada, falta manuscrito. |

## BOM activa

La BOM limpia para publicación HardwareX del elevador está en:

```text
docs/bom/hardwarex_elevator_bom_final.csv
```

La versión legible en GitHub está en:

```text
docs/bom/hardwarex_elevator_bom_final.md
```

Trazabilidad de la BOM:

```text
docs/bom/README.md
```

Resumen actual:

- 32 ítems de BOM + 1 fila de total estimado.
- Fuente: Google Sheet `ASM_Elevator_System_HardwareX_BOM`, tab `BOM_Final_Clean`.
- CAD asociado en la fuente: `ASM_Elevator_System.step` + `ASM_Elevator_System.f3z`, release v54.
- Moneda: USD estimados.
- Total estimado de producto/material: USD 484.78.
- No incluye envío, aduanas, impuestos ni cambios de precio de marketplace.
- Raspberry Pi 5 conserva costo estimado hasta confirmar vendedor/producto exacto.
- `docs/bom_template.csv` se conserva solo como referencia anterior en formato español/PEN.

El costo estimado es preliminar y debe revisarse antes de publicación/compra final.

## Pendientes inmediatos

1. Confirmar los nombres finales y exportaciones de esquemáticos.
2. Probar entry points principales de ROS 2:

```bash
ros2 run can_comm_pkg control_teclado
ros2 run can_comm_pkg can_traj
ros2 run can_comm_pkg can_slider
ros2 run can_comm_pkg ik_node
ros2 run can_comm_pkg j5_ramp
ros2 run can_comm_pkg j5_trap
```

3. Verificar que no haya artefactos versionados:

```bash
git ls-files | grep -E '(^|/)(build|install|log|\.idea|\.vscode)(/|$)'
```

4. Completar fotos y tabla final de conectores en electrónica.
5. Completar CAD/STEP/STL en `hardware/`.
6. Curar videos y datos hacia `validation/`.
7. Re-exportar `docs/bom/hardwarex_elevator_bom_final.csv` si cambia el Google Sheet fuente o el CAD agrega componentes.

## Criterio de cierre para HardwareX

La versión estará lista para manuscrito cuando:

- firmware J1-J5 compile desde un clon limpio;
- ROS 2 compile desde un clon limpio;
- `can_node` funcione con CAN virtual y físico;
- electrónica tenga esquemáticos, pinouts, conectores y fotos suficientes;
- la BOM permita comprar o sustituir componentes;
- validación tenga datos, videos y figuras curadas;
- mecánica tenga CAD/STEP/STL o se declare como pendiente crítico.

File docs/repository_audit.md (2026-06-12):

# Auditoría de avance del repositorio

Este documento resume el estado del repositorio público `assistbelle-arm-elevator-subsystem` y las mejoras pendientes antes del manuscrito.

## Índice

- [Estado general](#estado-general)
- [Avances confirmados](#avances-confirmados)
- [Pendientes prioritarios](#pendientes-prioritarios)
- [Criterio de cierre](#criterio-de-cierre)

## Estado general

| Área | Estado | Ubicación |
|---|---|---|
| Estructura general | Avanzada | [`../README.md`](../README.md), [`repository_structure.md`](repository_structure.md) |
| Documentación | Avanzada | [`./`](./) |
| Firmware ESP32 | Avanzado | [`../firmware/`](../firmware/) |
| ROS 2 | Avanzado | [`../ros2_ws/`](../ros2_ws/) |
| Electrónica | Parcial avanzada | [`../electronics/`](../electronics/) |
| Esquemáticos | En proceso de cierre | [`../electronics/schematics/schematics_index.md`](../electronics/schematics/schematics_index.md) |
| BOM | Inicial completa | [`bom_template.csv`](bom_template.csv) |
| CAD y mecánica | Pendiente crítico | [`../hardware/`](../hardware/) |
| Validación | Estructura lista | [`../validation/`](../validation/) |
| Paper | Pendiente | [`../paper/`](../paper/) |
| Licencias | Inicial listo | [`../LICENSE`](../LICENSE), [`../CITATION.cff`](../CITATION.cff) |

## Avances confirmados

### Firmware

- Proyectos ESP-IDF J1, J2, J3, J4 y J5 migrados a `firmware/`.
- J5 documentado con TB6600.
- DRV8871 documentado como driver de motores DC.
- ESP-IDF queda fuera del repositorio como dependencia externa.

### ROS 2

- `can_comm_pkg` compila localmente.
- `can_node` inicia con `can0` virtual.
- Entry points principales documentados para validación.

### Electrónica

- Raspberry Pi + MCP2515 documentado.
- Bus principal documentado en texto.
- Nodos controladores relacionados con actuadores y drivers.
- Carpeta de esquemáticos activa y con índice.
- Falta cerrar fotos, conectores y revisión cruzada con firmware.

### BOM

- BOM convertida a CSV ordenado.
- Componentes no usados retirados: Astra, Astra Plus, batería LiPo, tablet y DRV8825.
- Precios referenciales agregados.
- Drivers finales separados: DRV8871 para DC y TB6600 para NEMA23/J5.

## Pendientes prioritarios

1. Revisar e indexar esquemáticos finales.
2. Probar entry points ROS 2.
3. Mover o enlazar evidencias seleccionadas hacia `validation/`.
4. Crear figuras finales de validación.
5. Completar tabla de conectores y fotos de electrónica.
6. Completar CAD, STEP, STL y planos.
7. Preparar figuras/tablas para `paper/`.
8. Traducir documentación clave al inglés técnico.

## Criterio de cierre

El repositorio estará listo para comenzar el manuscrito cuando:

- firmware J1-J5 compile desde un clon limpio;
- ROS 2 compile desde un clon limpio;
- `can_node` funcione con CAN virtual y físico;
- electrónica tenga esquemáticos, pinouts, conectores y fotos suficientes;
- BOM esté revisada;
- validación tenga videos, datos y figuras curadas;
- mecánica tenga CAD/STEP/STL o se declare claramente como pendiente crítico.

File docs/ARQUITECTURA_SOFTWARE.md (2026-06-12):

# Arquitectura de Software

## 🧩 Grafo de Nodos

```mermaid
graph TD
    User[Usuario / Script] -->|/can_command| CANNode
    CANNode -->|Bus CAN| Motors[Motores del Robot]
    Motors -->|Bus CAN| CANNode
    CANNode -->|/joint_states| Rviz[Rviz / Visualización]
    CANNode -->|/motors_state| Plotter[Graficador de Datos]
    
    subgraph "Dominio ROS 2"
        CANNode(can_node)
        CLI(can_cli)
        Traj(can_traj)
        Tests(Pruebas de Rendimiento)
    end
```

## 📡 Protocolo CAN

El sistema utiliza un protocolo personalizado sobre tramas CAN.

### IDs de Mensaje

El ID CAN se compone de un **Prefijo** (Acción) y un **Sufijo** (ID del Motor).
`ID = (Prefijo << 4) | IDMotor`

| Prefijo | Hex | Acción | Formato del Payload |
| :--- | :--- | :--- | :--- |
| **A** | `0xA0` | **Solicitud Info** | Vacío |
| **B** | `0xB0` | **Feedback** | `float32 pos, float32 vel` (8 bytes) |
| **C** | `0xC0` | **Setpoint** | Varía (ver abajo) |
| **D** | `0xD0` | **Config/Modo** | `float32 valor` |

### Formatos de Setpoint (Prefijo C)

*   **Articulaciones Rotacionales (J1-J4)**:
    *   Payload: `[float32 Posición, float32 Velocidad]`
    *   Unidad: Radianes, Radianes/seg
*   **Articulación Lineal (J5)**:
    *   Payload: `[float32 Posición]`
    *   Unidad: Milímetros
*   **Gripper (J6)**:
    *   Payload: `[uint8 PWM]`
    *   Rango: 0-255

## 📨 Tópicos ROS 2

### Suscritos
*   **`/can_command`** (`std_msgs/msg/String`)
    *   Formato: `"<Acción><Motor>:<Payload>"`
    *   Ejemplos:
        *   `"C1:1.57,0.5"` (Mover J1 a 1.57 rad a 0.5 rad/s)
        *   `"C5:100.0"` (Mover J5 a 100 mm)
        *   `"A1"` (Solicitar info de J1)

### Publicados
*   **`/joint_states`** (`sensor_msgs/msg/JointState`)
    *   Mensaje estándar de ROS para visualización del robot.
*   **`/motors_state`** (`std_msgs/msg/Float32MultiArray`)
    *   Array plano: `[p1, p2, p3, p4, p5, v1, v2, v3, v4, v5]`

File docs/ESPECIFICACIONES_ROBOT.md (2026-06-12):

# Especificaciones del Robot

## 🦾 Límites de Articulaciones

El robot consiste en una base prismática (J5/Ascensor) y un brazo articulado de 4 grados de libertad (J1-J4).

| Articulación | Tipo | Nombre | Límite Min | Límite Max | Unidad |
| :--- | :--- | :--- | :--- | :--- | :--- |
| **J1** | Revoluta | Base | -135° | +34° | Grados |
| **J2** | Revoluta | Hombro | -45° | +70° | Grados |
| **J3** | Revoluta | Codo | -140° | +120° | Grados |
| **J4** | Revoluta | Muñeca | -180° | +180° | Grados |
| **J5** | Prismática | Ascensor | 0 mm | 350 mm | Milímetros |

> **Nota**: J5 es físicamente el ascensor base, pero a menudo se direcciona como índice 5 o 0 en diferentes contextos. En el protocolo CAN, es el Motor 5.

## 📐 Parámetros Denavit-Hartenberg (DH)

La cadena cinemática se define de la siguiente manera:

| Eslabón | $\theta$ (Offset) | $d$ (m) | $a$ (m) | $\alpha$ (rad) |
| :--- | :--- | :--- | :--- | :--- |
| **0 (Ascensor)** | 0 | $d_0 + 0.4$ | 0 | 0 |
| **1 (Base)** | $\theta_1 + 360^\circ$ | 0 | 0 | -90° |
| **2 (Fijo)** | $180^\circ$ | 0.1 | 0 | 0 |
| **3 (Hombro)** | $\theta_2 + 180^\circ$ | 0 | 0.215 | 0 |
| **4 (Codo)** | $\theta_3$ | 0 | 0.25 | 180° |
| **5 (Muñeca)** | $\theta_4$ | 0 | 0.125 | 90° |

## 🔌 Interfaz de Hardware

*   **Bus**: CAN Bus (Controller Area Network)
*   **Bitrate**: 1 Mbps (típico)
*   **Interfaz**: `can0` (SocketCAN)
*   **Motores**: Actuadores personalizados con controladores integrados.

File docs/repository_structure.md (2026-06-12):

# Estructura del repositorio

Este archivo define la estructura de trabajo para la rama hardwarex-publication-package.

## Reglas principales

- El codigo de ROS 2 se mantiene en ros2_ws.
- No duplicar paquetes, nodos ni scripts ROS 2 dentro de software.
- El firmware ESP32 final debe ir en firmware.
- Codigo_esp32 se conserva solo como fuente temporal para migrar codigo.
- Los resultados historicos pueden quedarse en resultados.
- Los datasets limpios y publicables deben ir en validation.

## Carpetas principales

- README.md
- requirements.txt
- docs
- hardware
- electronics
- firmware
- ros2_ws
- software
- validation
- paper
- Codigo_esp32
- resultados

## Responsabilidad por carpeta

- hardware: CAD mecanico, STEP, STL, planos, fasteners y fotos mecanicas.
- electronics: esquematicos, cableado, pinouts, potencia e imagenes de electronica.
- firmware: codigo fuente ESP32 y notas del protocolo CAN.
- ros2_ws: workspace ROS 2 completo.
- software: guias de instalacion y scripts auxiliares que no sean ROS 2.
- validation: datasets curados, graficas de validacion y referencias a videos.
- paper: manuscrito, figuras, tablas y referencias.
- docs: manuales, checklists, BOM y documentacion general.

## Reglas de migracion

1. Migrar firmware ESP32 desde Codigo_esp32 hacia firmware.
2. Mantener todo el codigo ROS 2 dentro de ros2_ws.
3. Copiar solo datos curados desde resultados hacia validation.
4. Colocar figuras finales del manuscrito en paper/figures.
5. Usar carpetas mecanicas en minuscula: hardware/cad, hardware/step y hardware/stl.

## Carpetas antiguas

No agregar archivos nuevos en hardware/CAD_editable, hardware/STEP ni hardware/STL.

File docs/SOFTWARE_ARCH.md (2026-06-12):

# Software Architecture

## 🧩 Node Graph

```mermaid
graph TD
    User[User / Script] -->|/can_command| CANNode
    CANNode -->|CAN Bus| Motors[Robot Motors]
    Motors -->|CAN Bus| CANNode
    CANNode -->|/joint_states| Rviz[Rviz / Visualization]
    CANNode -->|/motors_state| Plotter[Data Plotter]
    
    subgraph "ROS 2 Domain"
        CANNode(can_node)
        CLI(can_cli)
        Traj(can_traj)
        Tests(Performance Tests)
    end
```

## 📡 CAN Protocol

The system uses a custom protocol over CAN frames.

### Message IDs

The CAN ID is composed of a **Prefix** (Action) and a **Suffix** (Motor ID).
`ID = (Prefix << 4) | MotorID`

| Prefix | Hex | Action | Payload Format |
| :--- | :--- | :--- | :--- |
| **A** | `0xA0` | **Info Request** | Empty |
| **B** | `0xB0` | **Feedback** | `float32 pos, float32 vel` (8 bytes) |
| **C** | `0xC0` | **Setpoint** | Varies (see below) |
| **D** | `0xD0` | **Config/Mode** | `float32 value` |

### Setpoint Formats (Prefix C)

*   **Rotational Joints (J1-J4)**:
    *   Payload: `[float32 Position, float32 Velocity]`
    *   Unit: Radians, Radians/sec
*   **Linear Joint (J5)**:
    *   Payload: `[float32 Position]`
    *   Unit: Millimeters
*   **Gripper (J6)**:
    *   Payload: `[uint8 PWM]`
    *   Range: 0-255

## 📨 ROS 2 Topics

### Subscribed
*   **`/can_command`** (`std_msgs/msg/String`)
    *   Format: `"<Action><Motor>:<Payload>"`
    *   Examples:
        *   `"C1:1.57,0.5"` (Move J1 to 1.57 rad at 0.5 rad/s)
        *   `"C5:100.0"` (Move J5 to 100 mm)
        *   `"A1"` (Request info from J1)

### Published
*   **`/joint_states`** (`sensor_msgs/msg/JointState`)
    *   Standard ROS message for robot visualization.
*   **`/motors_state`** (`std_msgs/msg/Float32MultiArray`)
    *   Flat array: `[p1, p2, p3, p4, p5, v1, v2, v3, v4, v5]`

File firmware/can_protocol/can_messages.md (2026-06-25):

# Mensajes CAN del sistema

Este documento resume el protocolo CAN actualmente documentado para el subsistema brazo/elevador de Assistbelle y cruza la tesis, firmware ESP32 y ROS 2.

## Convención de IDs

La tesis describe conceptualmente el formato:

```text
ID = 0xn00m
```

En la implementación actual de ROS 2 y firmware ESP32, los IDs usados en SocketCAN/TWAI son IDs estándar de 11 bits en formato corto:

```text
A1..A6, B1..B5, C1..C6, D1..D2
```

En código, `can_node.py` calcula el ID como:

```text
A: 0xA0 | motor
B: 0xB0 | motor
C: 0xC0 | motor
D: 0xD0 | motor
```

Por ejemplo, `C5` se transmite como `0xC5` y `A6` como `0xA6`.

## Tipos de mensajes

| Tipo | Dirección | ID actual | Función |
|---|---|---|---|
| A | Maestro a nodo | `0xA1` a `0xA5`, broadcast `0xA6` | Solicitud de estado. |
| B | Nodo a maestro | `0xB1` a `0xB5` | Respuesta de estado. |
| C | Maestro a nodo | `0xC1` a `0xC5`, auxiliar `0xC6` | Comando de actuador. |
| D | Maestro a nodo | `0xD1`, `0xD2` | Comandos generales / gripper. |

## Payload estándar recomendado

Para mantener compatibilidad entre ROS 2 y firmware final, se recomienda congelar estos payloads:

| Mensaje | ID | DLC | Payload | Unidad | Endianness | Estado |
|---|---:|---:|---|---|---|---|
| Solicitud estado J1 | `0xA1` | 0 | Sin payload | - | - | Implementado en ROS 2. |
| Solicitud estado J2 | `0xA2` | 0 | Sin payload | - | - | Implementado en ROS 2. |
| Solicitud estado J3 | `0xA3` | 0 | Sin payload | - | - | Implementado en ROS 2. |
| Solicitud estado J4 | `0xA4` | 0 | Sin payload | - | - | Implementado en ROS 2. |
| Solicitud estado J5 | `0xA5` | 0 | Sin payload | - | - | Implementado en ROS 2 y firmware J5. |
| Broadcast solicitud | `0xA6` | 0 | Sin payload | - | - | Implementado en ROS 2 y firmware J5. |
| Estado J1-J4 | `0xB1`-`0xB4` | 8 | `float32 position`, `float32 velocity` | rad, rad/s | little-endian | Estándar ROS 2 esperado. |
| Estado J5 recomendado | `0xB5` | 8 | `float32 position`, `float32 velocity` | mm, mm/s | little-endian | Recomendado para compatibilidad final ROS 2. |
| Comando J1-J4 | `0xC1`-`0xC4` | 8 | `float32 target_position`, `float32 target_velocity` | rad, rad/s | little-endian | Implementado en ROS 2. |
| Comando J5 | `0xC5` | 4 | `float32 target_position` | mm | little-endian | Implementado en ROS 2 y aceptado por firmware J5. |
| Auxiliar / reset J5 | `0xC6` | 1 | `uint8 command` | adimensional | byte | Implementado en ROS 2 como auxiliar; semántica final pendiente. |
| Modo de control | `0xD1` | 4 | `float32 mode/value` | adimensional | little-endian | Requiere cierre semántico final. |
| Gripper | `0xD2` | 4 | `float32 opening_percent` | % | little-endian | Documentado para efector final. |

## Estado actual de compatibilidad J5

### ROS 2 actual

`can_node.py` envía `C5` como un solo `float32` little-endian en milímetros:

```text
C5:<target_mm>  ->  payload = struct.pack('<f', target_mm)
```

También interpreta todo mensaje `B1..B5` con DLC >= 8 como:

```text
position, velocity = struct.unpack('<ff', payload[:8])
```

Por eso, para J5, ROS 2 espera:

```text
B5 = float32 position_mm + float32 velocity_mm_s
```

### Firmware J5 actual

El firmware J5 actual acepta `C5` en dos formatos:

| Formato recibido | Interpretación |
|---|---|
| DLC = 4 | `float32` little-endian, redondeado a mm. |
| DLC >= 2 | `int16` big-endian, mm. |

Para `A5` o `A6`, el firmware responde `B5` con DLC = 8:

```text
bytes 0..3 = float32 position_mm little-endian
bytes 4..7 = 04 00 00 80
```

Esto reporta correctamente la posición, pero **no es totalmente compatible con la expectativa actual de ROS 2**, porque ROS 2 interpreta los bytes 4..7 como `float32 velocity`.

## Recomendación de cierre

Para cerrar el protocolo antes de HardwareX, se recomienda una de estas dos opciones:

### Opción A — recomendada

Actualizar firmware J5 para que `B5` responda:

```text
bytes 0..3 = float32 position_mm little-endian
bytes 4..7 = float32 velocity_mm_s little-endian
```

Si no se mide velocidad de J5, enviar `0.0f` como velocidad.

Ventaja: no requiere casos especiales en ROS 2 y mantiene el mismo formato `B1..B5`.

### Opción B

Mantener firmware J5 como está y modificar `can_node.py` para tratar `B5` como caso especial:

```text
B5 bytes 0..3 = position_mm
B5 bytes 4..7 = status/reserved
```

Ventaja: conserva firmware actual. Desventaja: rompe la uniformidad del protocolo y requiere documentar bytes reservados.

## Parámetros J5 relevantes

| Parámetro | Valor actual en firmware J5 | Observación |
|---|---:|---|
| Motor | NEMA 23 | Dos motores controlados por dos TB6600. |
| Driver | TB6600 x2 | `PUL`, `DIR`, `ENA` compartidos en paralelo por diseño. |
| Lead screw | T8, lead 8 mm | Usado para convertir pasos a mm. |
| Full steps/rev | 200 | Firmware. |
| Microstep actual | 1 | Según DIP S1=1, S2=1, S3=0 en firmware. |
| Pulses/mm actual | 25 | `(200 * microstep) / 8`. |
| Pulse rate | 500 pulses/s | `SPEED_HZ`. |
| CAN bitrate | 500 kbit/s | TWAI / SocketCAN. |

## Pendientes

- Confirmar físicamente el voltaje de alimentación de ambos TB6600.
- Decidir si se aplicará la opción A o B para `B5`.
- Confirmar semántica final de `C6`.
- Confirmar si `D2` responde solo en J4/gripper o en otro nodo final.
- Documentar límites de seguridad J5: mínimo, máximo, homing y fin de carrera si aplica.

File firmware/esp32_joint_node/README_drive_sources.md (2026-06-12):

# Fuentes de firmware ESP32 desde Drive

Esta carpeta documenta los codigos ESP32 encontrados en la carpeta de Drive compartida por el proyecto.

## Carpeta fuente revisada

- Drive: `JointVelocityControllers`
- Subcarpetas encontradas: `J1`, `J2`, `J3`, `J4`, `components`.

## Estructura detectada por articulacion

Cada articulacion contiene una estructura de proyecto ESP-IDF similar:

```text
Jx/
├── CMakeLists.txt
├── sdkconfig
├── main/
│   ├── CMakeLists.txt
│   ├── main.c
│   ├── node_config.h
│   ├── twai_comms.h
│   ├── base_libs.h
│   ├── encoder_driver.h
│   ├── motor_driver.h
│   └── pid_controller.h
└── build/              # no subir a GitHub
```

En J2, J3 y J4 tambien aparecen archivos relacionados al gripper cuando el proyecto incluye esa logica.

## Regla para GitHub

No se deben subir carpetas `build/`, `.vscode/`, `.devcontainer/`, `sdkconfig.old` ni archivos generados. Solo se deben versionar:

- `CMakeLists.txt`
- `sdkconfig` si es necesario para reproducibilidad
- `main/*.c`
- `main/*.h`
- `README.md`

## Estado

Se creo esta guia porque la carpeta de Drive contiene los proyectos completos, pero la importacion directa de archivos `.c` y `.h` desde Drive no entrega el texto en el conector. Para cerrar esta parte, copiar localmente los archivos fuente desde Drive a esta carpeta y hacer commit.

## Comando local recomendado

```bash
cd ~/robot-project
git checkout hardwarex-publication-package
mkdir -p firmware/esp32_joint_node/J1 firmware/esp32_joint_node/J2 firmware/esp32_joint_node/J3 firmware/esp32_joint_node/J4
# Copiar desde Drive solo CMakeLists.txt, sdkconfig y main/*.c main/*.h
# No copiar build/ ni .vscode/
git add firmware/esp32_joint_node
git commit -m "Add ESP32 joint firmware sources from Drive"
git push origin hardwarex-publication-package
```

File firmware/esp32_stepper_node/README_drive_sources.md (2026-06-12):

# Fuentes de firmware ESP32 del elevador desde Drive

Esta carpeta documenta los codigos ESP32 encontrados para el eje prismatico J5 / sistema de elevacion.

## Carpeta fuente revisada

- Drive: `JointPositionControllers`
- Subcarpetas encontradas:
  - `twai_id_based_basedness`
  - `codigo para diferentes nodos`

## Archivos detectados

En `twai_id_based_basedness` se encontro un proyecto ESP-IDF con:

```text
twai_id_based_basedness/
├── CMakeLists.txt
├── sdkconfig
└── main/
    ├── CMakeLists.txt
    ├── twai_id_based_basedness.c
    └── Kconfig.projbuild
```

En `codigo para diferentes nodos` se encontraron archivos C separados:

```text
nodo1.c
nodo2.c
nodo3.c
nodo4.c
```

## Interpretacion actual

Esta carpeta parece contener codigo de posicionamiento y pruebas por IDs TWAI/CAN. Puede servir como base para documentar el control del elevador y/o nodos individuales.

## Regla para GitHub

No subir carpetas `build/`, `.vscode/`, `.devcontainer/` ni archivos generados. Solo subir codigo fuente y configuracion necesaria.

## Pendiente critico

- Confirmar cual archivo corresponde realmente al nodo J5 del elevador.
- Confirmar pines STEP, DIR y EN usados para los drivers TB6600 o DRV8825.
- Confirmar si el sistema final usa TB6600, DRV8825 o ambos en etapas distintas.
- Confirmar unidad interna de posicion: pasos, milimetros o metros.

## Comando local recomendado

```bash
cd ~/robot-project
git checkout hardwarex-publication-package
mkdir -p firmware/esp32_stepper_node/J5
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

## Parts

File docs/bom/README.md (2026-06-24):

<!-- SPDX-License-Identifier: CC-BY-4.0 -->

# Bill of materials

This folder stores the curated bill of materials (BOM) files for the Assistbelle elevator/arm HardwareX package.

## Recommended reading order

1. Open [`hardwarex_elevator_bom_final.md`](hardwarex_elevator_bom_final.md) for the readable GitHub-rendered BOM.
2. Open [`hardwarex_elevator_bom_final.csv`](hardwarex_elevator_bom_final.csv) for the complete machine-readable/source table.
3. Use [`../bom_template.csv`](../bom_template.csv) only as the previous Spanish/PEN reference BOM.

## Files

| File | Purpose | Source | Status |
|---|---|---|---|
| [`hardwarex_elevator_bom_final.md`](hardwarex_elevator_bom_final.md) | Human-readable Markdown summary with category subtotals, compact tables and CAD naming guide. | Generated from `hardwarex_elevator_bom_final.csv`. | Current readable BOM for GitHub reviewers. |
| [`hardwarex_elevator_bom_final.csv`](hardwarex_elevator_bom_final.csv) | Final clean BOM export for the elevator CAD v54 review, synchronized with the Google Sheet. | Google Sheet `ASM_Elevator_System_HardwareX_BOM`, tab `BOM_Final_Clean`, spreadsheet ID `13egV0GarW81nshgVwWWbSk6_NnhDDFxmWRa8S5-cg0I`. | Current exported BOM snapshot. |
| [`../bom_template.csv`](../bom_template.csv) | Previous active public BOM template in Spanish/PEN format. | Earlier procurement reconciliation work. | Retained for continuity; superseded for the elevator-specific HardwareX BOM by `hardwarex_elevator_bom_final.csv`. |

## Source snapshot

| Field | Value |
|---|---|
| Source workbook title | `ASM_Elevator_System_HardwareX_BOM` |
| Source tab | `BOM_Final_Clean` |
| CAD inputs noted in source workbook | `ASM_Elevator_System.step` and `ASM_Elevator_System.f3z` |
| CAD release noted in source workbook | `v54` |
| Source-generated date | `2026-06-23` |
| Last repository BOM update | `2026-06-23` |
| BOM rows | 32 item rows + 1 estimated-total row |
| Estimated product/material total | USD 484.78 |
| Currency | USD estimates |
| Exchange-rate note | Local PEN prices converted at 1 USD = 3.3898 PEN where applicable |
| Cost coverage | Product/material cost only; shipping, customs, taxes and marketplace price changes excluded. |

## Counting rule

Purchased subassemblies are counted at the procurement level. Internal V-wheel CAD subparts are excluded to avoid double counting. This follows the note in the source workbook README tab.

## Supplier-reference rule

The current CSV keeps one `Purchase URL` column with the selected source for each item. Source handling follows these rules:

1. Prefer exact AliExpress product links when the exact purchased or equivalent product is identifiable.
2. Use Peru/local suppliers such as Naylamp when they are active and useful for replication.
3. Use McMaster-Carr direct links for CAD-coded standard fasteners.
4. For fabricated parts, include local material or fabrication-service references, then document actual prototype cost in the remarks.

## CAD naming rule

CAD browser/component names should start with the matching BOM item ID when possible. The current electronics additions use:

| BOM ID | CAD name pattern |
|---|---|
| `BUY_ELE_001` | `BUY_ELE_001_RaspberryPi5_8GB_SBC` |
| `BUY_ELE_002` | `BUY_ELE_002_MCP2515_CAN_SPI_Module` |
| `BUY_ELE_003` | `BUY_ELE_003_TB6600_Stepper_Driver_J5_MotorA` and `BUY_ELE_003_TB6600_Stepper_Driver_J5_MotorB` |

## Review notes before publication

- Confirm stock, pack size and shipping before purchasing; prices are references and may change.
- Review odd or CAD-derived quantities such as `STD_FAS_010` and `STD_FAS_011` against the final CAD assembly.
- Confirm whether the two TB6600 drivers correspond to left/right or Motor A/Motor B in the final wiring diagram.
- Replace the Raspberry Pi 5 estimate with an exact selected supplier link when available.
- Keep private raw receipts, reimbursement sheets and order screenshots out of the public repository unless they are redacted.
- If a row changes in the Google Sheet or CAD adds/removes components, re-export/update the CSV snapshot and regenerate the Markdown summary in the same commit.

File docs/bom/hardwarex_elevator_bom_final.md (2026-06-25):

<!-- SPDX-License-Identifier: CC-BY-4.0 -->

# HardwareX Elevator BOM

Readable bill of materials for the Assistbelle vertical elevator subsystem, prepared for the HardwareX publication package.

The complete machine-readable source table is available in [`hardwarex_elevator_bom_final.csv`](hardwarex_elevator_bom_final.csv). This Markdown file is a human-readable summary for GitHub navigation and reviewer readability.

## Snapshot

| Metric | Value |
|---|---:|
| BOM item rows | 32 |
| Estimated product/material total | USD 484.78 |
| Currency | USD estimates |
| Exchange-rate note | Local PEN prices converted at 1 USD = 3.3898 PEN where applicable |
| Cost coverage | Product/material cost only |
| Excluded costs | Shipping, customs, taxes and marketplace price changes |
| Source workbook | `ASM_Elevator_System_HardwareX_BOM` |
| Source tab | `BOM_Final_Clean` |
| Source CAD release | `ASM_Elevator_System.step` + `ASM_Elevator_System.f3z`, v54 source sheet; current uploaded CAD working snapshot is v60 |
| Export/update date | 2026-06-23 |

## Category summary

| Category | Items | Estimated subtotal |
|---|---:|---:|
| Structure | 6 | USD 122.14 |
| Actuation | 6 | USD 81.58 |
| Guiding | 3 | USD 78.30 |
| Fasteners | 13 | USD 37.51 |
| Electronics | 3 | USD 165.25 |
| **Total** | **32** | **USD 484.78** |

## Structure

| ID | Part | Type | Qty | Material | Supplier | Total |
|---|---|---|---:|---|---|---:|
| `BUY_STR_001` | V-Slot 20x40 vertical rail, 600 mm | Purchased | 2 pcs | Anodized aluminum | Naylamp Mechatronics | USD 24.78 |
| `BUY_STR_002` | V-Slot L bracket, 20 mm | Purchased | 24 pcs | Aluminum 6105-T5 | Naylamp Mechatronics | USD 23.28 |
| `BUY_STR_003` | V-Slot L bracket, 40 mm | Purchased | 10 pcs | Aluminum 6105-T5 | Naylamp Mechatronics | USD 13.60 |
| `BUY_STR_004` | V-Slot 20x40 top crossbar, 500 mm | Purchased | 1 pc | Anodized aluminum | Naylamp Mechatronics | USD 10.33 |
| `FAB_STR_001` | Base plate, 356 x 356 x 15 mm | Fabricated | 1 pc | MDF | Local fabrication | USD 5.90 |
| `FAB_STR_002` | Top plate, 420 x 400 x 3 mm | Fabricated | 1 pc | Stainless steel | Local fabrication | USD 44.25 |

## Actuation

| ID | Part | Type | Qty | Material | Supplier | Total |
|---|---|---|---:|---|---|---:|
| `BUY_ACT_001` | NEMA 23 stepper motor JK57HS51-2804 | Purchased | 2 pcs | Commercial motor | AliExpress | USD 20.36 |
| `BUY_ACT_002` | TR8x8 lead screw, 550 mm | Purchased | 2 pcs | Steel | AliExpress | USD 38.90 |
| `BUY_ACT_003` | Flexible coupler, 6.35 x 8 mm | Purchased | 2 pcs | Aluminum | Naylamp Mechatronics | USD 8.86 |
| `BUY_ACT_004` | T8 lead screw nut, lead 8 mm | Purchased | 2 pcs | Brass/metal | AliExpress | USD 4.00 |
| `BUY_ACT_005` | TR8 nut block housing | Purchased | 2 pcs | Delrin/metal | Naylamp Mechatronics | USD 6.50 |
| `FAB_ACT_002` | NEMA 23 mounting plate | Fabricated | 2 pcs | ABS | Local fabrication | USD 2.96 |

## Guiding

| ID | Part | Type | Qty | Material | Supplier | Total |
|---|---|---|---:|---|---|---:|
| `BUY_GUI_003` | V-wheel kit with bearings | Purchased | 8 pcs | Polycarbonate wheel + 625RS bearings | AliExpress - BULK-MAN 3D Official Store | USD 13.38 |
| `FAB_GUI_001` | Gantry plate, 127 x 88 x 3 mm | Fabricated | 4 pcs | Stainless steel | Local fabrication | USD 59.00 |
| `FAB_GUI_002` | Spacer block | Fabricated | 4 pcs | ABS, gray | Local fabrication | USD 5.92 |

## Fasteners

| ID | Part | Type | Qty | Supplier | Total |
|---|---|---|---:|---|---:|
| `STD_FAS_001` | Screw, McMaster 90258A232 | Standard hardware | 12 pcs | McMaster-Carr | USD 2.33 |
| `STD_FAS_002` | Screw, McMaster 92125A192 | Standard hardware | 8 pcs | McMaster-Carr | USD 1.02 |
| `STD_FAS_003` | Hex nut, McMaster 90592A090 | Standard hardware | 8 pcs | McMaster-Carr | USD 0.17 |
| `STD_FAS_004` | Socket head screw, McMaster 92290A148 | Standard hardware | 8 pcs | McMaster-Carr | USD 2.98 |
| `STD_FAS_005` | Shim, McMaster 96945A303 | Standard hardware | 12 pcs | McMaster-Carr | USD 9.77 |
| `STD_FAS_006` | Hex nut, McMaster 90592A011 | Standard hardware | 50 pcs | McMaster-Carr | USD 1.00 |
| `STD_FAS_007` | Thread-forming screw, McMaster 99461A973 | Standard hardware | 10 pcs | McMaster-Carr | USD 3.88 |
| `STD_FAS_008` | M5 wheel spacer | Standard hardware | 16 pcs | Naylamp Mechatronics | USD 2.88 |
| `STD_FAS_009` | Truss head screw, McMaster 92467A517 | Standard hardware | 8 pcs | McMaster-Carr | USD 1.92 |
| `STD_FAS_010` | Flat head screw, McMaster 92125A208 | Standard hardware | 32 pcs | McMaster-Carr | USD 5.15 |
| `STD_FAS_011` | M5 T-slot nut for 2020 profile | Standard hardware | 32 pcs | Naylamp Mechatronics | USD 3.84 |
| `STD_FAS_012` | Pan head screw, McMaster 92000A220 | Standard hardware | 12 pcs | McMaster-Carr | USD 1.40 |
| `STD_FAS_013` | Thread-forming screw, McMaster 99461A971 | Standard hardware | 4 pcs | McMaster-Carr | USD 1.17 |

## Electronics

| ID | Part | Type | Qty | Supplier | Total |
|---|---|---|---:|---|---:|
| `BUY_ELE_001` | Raspberry Pi 5 single-board computer, 8 GB RAM | Purchased | 1 pc | AliExpress / Raspberry Pi supplier | USD 125.00 |
| `BUY_ELE_002` | MCP2515 CAN-SPI module | Purchased | 1 pc | AliExpress | USD 2.55 |
| `BUY_ELE_003` | TB6600 stepper motor driver module | Purchased | 2 pcs | AliExpress - FANGXIN Store | USD 37.70 |

## CAD naming guide

Use BOM-aligned names in the Fusion 360 browser to keep CAD, BOM and documentation traceable:

| Current CAD browser name | Recommended name |
|---|---|
| `RASPBERRY_PI_5_1 v2:1` | `BUY_ELE_001_RaspberryPi5_8GB_SBC` |
| `MCP2515 CAN_SPI v2:1` | `BUY_ELE_002_MCP2515_CAN_SPI_Module` |
| `TB6600(AP203) v1:1` | `BUY_ELE_003_TB6600_Stepper_Driver_J5_MotorA` |
| `TB6600(AP203) v1:2` | `BUY_ELE_003_TB6600_Stepper_Driver_J5_MotorB` |

## Source and supplier notes

- Exact sourcing links are preserved in the CSV file under `Purchase URL`.
- Purchased subassemblies are counted at the procurement level.
- Internal V-wheel CAD subparts are excluded to avoid double counting.
- McMaster-Carr part numbers are retained for CAD-coded standard fasteners.
- Fabricated part costs are prototype estimates and should be verified before final replication.
- `FAB_GUI_001` dimensions were updated to 127 x 88 x 3 mm from the current v60 CAD/drawing; the previous 20 x 80 mm description should be treated as outdated.
- Electronics lines `BUY_ELE_001` to `BUY_ELE_003` include the Raspberry Pi 5, MCP2515 CAN-SPI module and two TB6600 drivers shown in the CAD update.
- Raspberry Pi 5 cost is still an estimate until the exact seller/product screenshot is confirmed.

## Publication notes

Before final HardwareX submission:

- Confirm stock, shipping and pack sizes for all supplier links.
- Re-check CAD-derived fastener quantities, especially `STD_FAS_010` and `STD_FAS_011`.
- Confirm whether the two TB6600 drivers correspond to left/right or Motor A/Motor B in the final wiring diagram.
- Replace the Raspberry Pi 5 estimate with an exact selected supplier link when available.
- Keep private receipts, reimbursement files and raw order screenshots outside the public repository unless redacted.
- If the Google Sheet changes, re-export the CSV and regenerate this Markdown summary.

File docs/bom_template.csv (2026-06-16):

ID | Sistema | Categoría | Ítem | Cantidad | Unidad | Especificación | Función | Proveedor | Costo unitario PEN | Costo total PEN | Tipo fuente | URL fuente | Estado | Notas
BOM-001 | Brazo robótico | Actuadores | Reductor de engranaje helicoidal 50:1 | 1 | und | 50:1, eje 8 mm | Reducción mecánica | AliExpress | 94.53 | 94.53 | Drive | https://www.aliexpress.com/item/1005005137416396.html | Pedido online | Precio registrado en lista de materiales.
BOM-002 | Brazo robótico | Estructura | Barra de aluminio para insertos en plástico | 1 | und | 4 x 35 x 300 mm | Refuerzo/insertos mecánicos | AliExpress | 25.86 | 25.86 | Drive | https://www.aliexpress.com/item/1005005310803163.html | Pedido online | Precio registrado en lista de materiales.
BOM-003 | Brazo robótico | Actuadores | Eje de 8 mm | 1 | und | 500 mm, diámetro 8 mm | Eje mecánico de transmisión | AliExpress | 29.42 | 29.42 | Drive | https://es.aliexpress.com/item/1005005477259278.html | Pedido online | Precio registrado en lista de materiales.
BOM-004 | Brazo robótico | Estructura | Tubo PVC 1.5 pulg x 3 m | 1 | und | PVC SAP 1 1/2 x 3 m | Estructura auxiliar/prototipo | Promelsa | 25.87 | 25.87 | Drive | https://www.promelsa.com.pe/1028733-tubo-pvc-sap-1-1-2-x-3mts.html | Pedido online | Precio registrado en lista de materiales.
BOM-005 | Brazo robótico | Electrónica | Pack de 4 sensores de corriente ACS712 | 1 | pack | ACS712 5A, pack x4 | Sensado de corriente | AliExpress | 13.47 | 13.47 | Drive | https://www.aliexpress.com/item/1005007381850382.html | Pedido online | Precio registrado en lista de materiales.
BOM-006 | Brazo robótico | Actuadores | Rodajes de 8 mm | 1 | pack | 10 piezas | Soporte de ejes | AliExpress | 12.84 | 12.84 | Drive | https://www.aliexpress.com/item/1005005354547854.html | Pedido online | Precio registrado en lista de materiales.
BOM-007 | Brazo robótico | Estructura | Acoplamiento de eje 8 mm a 8 mm | 1 | pack | 2 piezas, 8-8 mm | Acoplamiento mecánico | AliExpress | 11.86 | 11.86 | Drive | https://www.aliexpress.com/item/1005007821266268.html | Pedido online | Precio registrado en lista de materiales.
BOM-008 | Brazo robótico | Percepción | Logitech Brio 4K | 1 | und | Webcam 4K USB | Visión / lectura / teleoperación | Store Games Perú | 599.00 | 599.00 | Referencia web | https://storegames.com.pe/producto/webcam-logitech-brio-4k-pro-color-negro/ | Referencial | Se mantiene porque no se indicó retirar Brio.
BOM-009 | Brazo robótico | Actuadores | Motor Pololu 37D 150:1 con encoder | 1 | und | 12 V, 150:1, 64 CPR encoder, item #2828 | Actuación de articulación | Pololu | 224.86 | 224.86 | Referencia web | https://www.pololu.com/product/2828 | Pedido a UTEC / referencial | Sustituye la línea UTEC Motor Pololu GB37-150 con modelo identificable y link de compra.
BOM-010 | Brazo robótico | Actuadores | Motor Pololu 37D 131:1 con encoder | 1 | und | 12 V, 131.25:1, 64 CPR encoder, item #4756 | Actuación de articulación | Pololu | 224.86 | 224.86 | Referencia web | https://www.pololu.com/product/4756 | Pedido a UTEC / referencial | Sustituye la línea UTEC Motor Pololu GB37-131 con modelo identificable y link de compra.
BOM-011 | Brazo robótico | Actuadores | Motor NFP-5840-31ZY-EN | 1 | und | 12 V, 8 rpm, 100 kg-cm, encoder | Actuación de articulación | MicroDCMotors | 110.70 | 110.70 | Drive | https://microdcmotors.com/product/12v-24v-high-torque-low-speed-dc-motor-with-encoder-self-locking-model-nfp-5840-31zy-en | Pedido online | Precio registrado en Drive.
BOM-012 | Brazo robótico | Actuadores | Motor NFP-36GP-555-EN | 1 | und | 12 V, 19:1, 630 rpm, 15 kg-cm, encoder | Actuación de articulación | MicroDCMotors | 158.67 | 158.67 | Drive | https://microdcmotors.com/product/micro-dc-gear-motor-12v-model-nfp-ga36y-555-ce-with-encoder | Pedido online | Precio registrado en Drive.
BOM-013 | Brazo robótico | Actuadores | Envío de motores del brazo | 1 | servicio | Envío internacional | Costo logístico | MicroDCMotors | 110.70 | 110.70 | Drive |  | Pedido online | Costo de envío registrado en Drive.
BOM-014 | Brazo robótico | Electrónica | Driver de motor DRV8871 | 1 | pack | Pack x4 | Driver para motores DC | AliExpress | 58.95 | 58.95 | Drive | https://es.aliexpress.com/item/1005007507633619.html | Pedido online | Driver final para motores DC según indicación del usuario.
BOM-015 | Brazo robótico | Actuadores | Rodaje radial 50x65x7 | 1 | pack | 2 piezas, modelo 6810-50x65x7 ZZ | Soporte rotativo | AliExpress | 26.74 | 26.74 | Drive | https://www.aliexpress.com/item/1005007212575557.html | Pedido online | Precio registrado en Drive.
BOM-016 | Brazo robótico | Actuadores | Rodaje axial 40x60x3 | 1 | und | 40 x 60 x 3 mm | Soporte axial | AliExpress | 11.51 | 11.51 | Drive | https://www.aliexpress.com/item/1005004695778540.html | Pedido online | Precio registrado en Drive.
BOM-017 | Brazo robótico / Ascensor | Electrónica | Módulo CAN SN65HVD230 | 1 | pack | Pack x6 | Transceptores CAN para ESP32 | AliExpress | 34.14 | 34.14 | Drive | https://es.aliexpress.com/item/1005008322059982.html | Pedido online | Precio registrado en Drive.
BOM-018 | Brazo robótico / Ascensor | Electrónica | Optoacopladores PC817C | 1 | pack | Pack x20 | Aislamiento/acondicionamiento de señales | AliExpress | 3.61 | 3.61 | Drive | https://www.aliexpress.com/item/1005006281381268.html | Pedido online | Precio registrado en Drive.
BOM-019 | Brazo robótico / Ascensor | Electrónica | ESP32 DevKit V1 / NodeMCU-32 | 5 | und | ESP32 30 pines USB-C | Control de nodos J1-J5 | Naylamp Mechatronics | 45.00 | 225.00 | Referencia web | https://naylampmechatronics.com/espressif-esp/1250-esp32-devkit-v1-nodemcu-32-30-pin-esp32-wifi-usb-c.html | Referencial | Cantidad funcional estimada: 5 nodos ESP32.
BOM-020 | Brazo robótico / Ascensor / Cara | Electrónica | Conversor DC-DC 5 A | 1 | und | Step-down 5 A | Regulación 12 V a 5 V | AliExpress | 3.80 | 3.80 | Drive | https://es.aliexpress.com/item/1005006648976219.html | Pedido online | Precio registrado en Drive.
BOM-021 | Brazo robótico / Ascensor / Cara | Estructura | Filamento ABS | 2 | kg | ABS 1.75 mm | Impresión 3D de piezas | Naylamp / UTEC | 120.00 | 240.00 | Referencia web | https://naylampmechatronics.com/filamentos/578-abs-negro-rollo-1kg-creality.html | Referencial | En Drive figura como provisto por UTEC; se asigna precio referencial por kg.
BOM-022 | Brazo robótico / Ascensor / Cara | Electrónica | Raspberry Pi 5 8GB + microSD | 1 | kit | Raspberry Pi 5 8GB + microSD | Control ROS 2 y visión | Electromanía / UTEC | 833.00 | 833.00 | Referencia web | https://www.electromania.pe/producto/raspberry-pi-5-8gb-ram/ | Referencial | Precio referencial de placa; microSD pendiente de costo específico.
BOM-023 | Brazo robótico / Ascensor / Cara | Herramienta | Cautín / soldador | 1 | und | Cautín portátil TS-80 o equivalente | Herramienta de ensamblaje | Naylamp Mechatronics | 550.00 | 550.00 | Referencia web | https://naylampmechatronics.com/herramientas/766-cautin-portatil-ts-80.html | Referencial | Se incluye como herramienta de laboratorio no componente instalado.
BOM-024 | Brazo robótico / Ascensor / Cara | Electrónica | Cables + jumpers | 1 | set | Dupont 10/20 cm y cable para protoboard | Conexiones de prototipo | Naylamp Mechatronics | 13.00 | 13.00 | Referencia web | https://naylampmechatronics.com/cables/447-cable-jumper-dupont-hembra-a-macho-10cm-20und.html | Referencial | Estimado con packs de jumpers de Naylamp.
BOM-025 | Brazo robótico / Ascensor / Cara | Electrónica | Protoboard 830 | 1 | und | 830 puntos | Prototipado electrónico | Naylamp Mechatronics | 10.00 | 10.00 | Referencia web | https://naylampmechatronics.com/protoboard/222-protoboard-830.html | Referencial | Precio referencial Naylamp.
BOM-026 | Brazo robótico / Ascensor / Cara | Herramienta | Multímetro ZOYI ZT98 | 1 | und | Autorango CAT III | Medición eléctrica | Naylamp Mechatronics | 65.00 | 65.00 | Referencia web | https://naylampmechatronics.com/multimetros/865-multimetro-zoyi-zt98.html | Referencial | Se incluye como herramienta de laboratorio.
BOM-027 | Brazo robótico / Ascensor / Cara | Electrónica | Interruptores / pulsadores | 3 | und | Pulsador con cubierta o switch equivalente | Entradas digitales / pruebas | Naylamp Mechatronics | 1.00 | 3.00 | Referencia web | https://naylampmechatronics.com/152-pulsadores | Referencial | Estimado como 3 pulsadores/switches.
BOM-028 | Brazo robótico / Ascensor / Cara | Electrónica | LEDs indicadores | 6 | und | 2 rojos, 2 amarillos, 2 verdes | Indicadores de estado | Naylamp Mechatronics | 0.40 | 2.40 | Referencia web | https://naylampmechatronics.com/accesorios-y-prototipado/1053-led-5mm-difuso-rojo.html | Referencial | Precio unitario de LED 5 mm difuso.
BOM-029 | Brazo robótico / Ascensor / Cara | Electrónica | Resistencias surtidas | 50 | und | 1/4 W: 220, 330, 1k, 4.7k, 10k y otros | Limitación de corriente / pull-up / pull-down | Naylamp Mechatronics | 0.10 | 5.00 | Referencia web | https://naylampmechatronics.com/resistencias/870-resistencia-1l4w-330-ohm.html | Referencial | Estimado de 50 resistencias a S/0.10.
BOM-030 | Brazo robótico / Ascensor / Cara | Electrónica | Cintas termorretráctiles | 1 | set | Varios diámetros | Aislamiento de cableado | Referencia local | 15.00 | 15.00 | Estimación |  | Referencial | Precio referencial por set; fuente exacta por confirmar.
BOM-031 | Brazo robótico / Ascensor / Cara | Estructura | Bridas | 1 | set | Bridas plásticas | Gestión de cableado | Donativo | 0.00 | 0.00 | Drive |  | Entregado | Entregado como donativo.
BOM-032 | Brazo robótico / Ascensor / Cara | Estructura | Juego de tuercas M3/M4/M5 | 1 | set | Tuercas varias | Ensamblaje mecánico | Naylamp Mechatronics / UTEC | 10.00 | 10.00 | Referencia web | https://naylampmechatronics.com/212-tuercas | Referencial | Costo mínimo referencial; completar cuando se defina CAD.
BOM-033 | Sistema de ascensor | Estructura | Tornillo eje Z trapezoidal T8 | 1 | kit | T8, 55 cm, diámetro 8 mm, paso 2 mm, acoplamiento, KL08 | Movimiento vertical | AliExpress | 35.40 | 35.40 | Drive | https://es.aliexpress.com/item/1005004052385590.html | Pedido online | Precio registrado en Drive.
BOM-034 | Sistema de ascensor | Actuadores | NEMA23 Stepper Motor | 2 | und | 2.8 A, ~1 N.m | Actuación elevador J5 | Sawers Perú | 90.00 | 180.00 | Drive | https://sawers.com.pe/nema23-stepper-motor-2-8a-1-8nm | Pedido online | Drive registra S/90; se considera S/90 por unidad para 2 motores.
BOM-035 | Sistema de ascensor | Estructura | Kit 10 ruedas Dual V | 1 | kit | Ruedas Dual V + 625ZZ + tornillos/arandelas/espaciadores | Guías V-slot | AliExpress | 40.34 | 40.34 | Drive | https://es.aliexpress.com/item/1005007067590716.html | Pedido online | Precio registrado en Drive; usuario confirma uso en sistema de ascensión.
BOM-036 | Sistema de ascensor | Estructura | Perfil V-Slot 2040 | 170 | cm | 60 cm + 60 cm + 50 cm | Marco del elevador | Naylamp | 120.00 | 120.00 | Drive | https://naylampmechatronics.com/perfiles-de-aluminio/694-perfil-v-slot-2040-x-centimetro.html | Pedido online | Usuario confirma que fue usado junto con V-Slot 2020; falta mapear ubicación exacta.
BOM-037 | Sistema de ascensor | Estructura | V-2040 ruedas frame kit | 3 | kit | Kit de ruedas/frame V-2040 | Guía del ascensor / referencia impresión 3D | AliExpress | 0.00 | 0.00 | Drive | https://es.aliexpress.com/item/1005004148228826.html | Entregado | Entregado; se indicó que se copiará modelo para impresión 3D.
BOM-038 | Sistema de ascensor | Electrónica | Driver TB6600 | 2 | und | TB6600 4.0 A | Driver final para motores NEMA23 | Naylamp Mechatronics | 100.00 | 200.00 | Referencia web | https://naylampmechatronics.com/driver-pap-stepper/1138-driver-pap-tb6600-4a.html | Referencial | Reemplaza DRV8825 como driver final del elevador.
BOM-039 | Sistema de ascensor | Estructura | Perfil V-Slot 2020 | 350 | cm | 70 cm x4 + 35 cm x2 | Marco/estructura complementaria del elevador | SAI SAC Mecatrónica | 0.45 | 157.50 | Drive |  | Pedido local / user-confirmed | Usuario confirma que se usó junto con V-Slot 2040; costo desde PRC-030; falta mapear ubicación exacta.
BOM-040 | Sistema de ascensor | Estructura | Brackets V-slot 90 grados | 16 | und | 6 unidades más 10 unidades de compras separadas | Uniones del marco V-slot | SAI SAC Mecatrónica | 7.81 | 125.00 | Drive |  | Pedido local / user-confirmed | Costo agregado preliminar desde PRC-023 y parte de PRC-033; dividir si se requiere precisión final.
BOM-041 | Sistema de ascensor | Estructura | Brackets universales doble L | 10 | und | Universal double L brackets | Uniones/refuerzos del marco | SAI SAC Mecatrónica | 7.50 | 75.00 | Drive |  | Pedido local / user-confirmed | Costo preliminar incluido junto con PRC-033; dividir costo entre brackets 90 y doble L si se requiere precisión.
BOM-042 | Sistema de ascensor | Estructura | Tornillos M5 y tuercas T para V-Slot | 1 | set | 40 tornillos + 40 tuercas T 2020 | Fijación de perfiles V-slot | SAI SAC Mecatrónica | 112.00 | 112.00 | Drive |  | Pedido local / cantidad pendiente | Linea preliminar desde PRC-031; incluye KP-08/acoples/brackets/fasteners en compra agrupada; dividir antes de publicación final.
BOM-043 | Sistema de ascensor | Estructura | Varilla roscada 3/16 y tuercas hexagonales | 1 | set | Varilla 1 m + caja x100 tuercas | Fijación/refuerzo mecánico | SODIMAC | 19.80 | 19.80 | Drive |  | Pedido local / user-confirmed | Usuario confirma uso; falta documentar función | largo instalado y cantidad de tuercas usadas.
BOM-044 | Sistema de ascensor | Estructura | Bloques KP-08 y acoples 6x6 | 1 | set | KP-08 bearing blocks + 6x6 couplings | Soporte/acoplamiento del sistema de ascensión | SAI SAC Mecatrónica | 0.00 | 0.00 | Drive |  | Pedido local / split pendiente | Incluido dentro de PRC-031; costo pendiente de separación porque la compra también incluye brackets y fasteners.

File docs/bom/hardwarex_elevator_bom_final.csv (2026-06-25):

Item ID | Category | Part name | Type | Quantity | Unit | Material | Process | Primary supplier | Purchase URL | Unit cost (USD) | Total cost (USD) | Remarks
BUY_STR_001 | Structure | V-Slot 20x40 vertical rail, 600 mm | Purchased | 2 | pcs | Anodized aluminum | Purchased cut-to-length extrusion | Naylamp Mechatronics | https://naylampmechatronics.com/perfiles-de-aluminio/694-perfil-v-slot-2040-x-centimetro.html | $12,39 | $24,78 | Verified: Naylamp S/0.70 per cm; 60 cm = S/42. Converted at 1 USD = 3.3898 PEN. Shipping/taxes excluded.
BUY_STR_002 | Structure | V-Slot L bracket, 20 mm | Purchased | 24 | pcs | Aluminum 6105-T5 | Purchased standard bracket | Naylamp Mechatronics | https://naylampmechatronics.com/v-slot/467-bracket-l-universal-simple.html | $0,97 | $23,28 | Verified: Naylamp S/3.30 each. Converted at 1 USD = 3.3898 PEN. Shipping/taxes excluded.
BUY_STR_003 | Structure | V-Slot L bracket, 40 mm | Purchased | 10 | pcs | Aluminum 6105-T5 | Purchased standard bracket | Naylamp Mechatronics | https://naylampmechatronics.com/v-slot/468-bracket-l-universal-doble.html | $1,36 | $13,60 | Verified: Naylamp S/4.60 each. Converted at 1 USD = 3.3898 PEN. Shipping/taxes excluded.
BUY_STR_004 | Structure | V-Slot 20x40 top crossbar, 500 mm | Purchased | 1 | pcs | Anodized aluminum | Purchased cut-to-length extrusion | Naylamp Mechatronics | https://naylampmechatronics.com/perfiles-de-aluminio/694-perfil-v-slot-2040-x-centimetro.html | $10,33 | $10,33 | Verified: Naylamp S/0.70 per cm; 50 cm = S/35. Converted at 1 USD = 3.3898 PEN. Shipping/taxes excluded.
FAB_STR_001 | Structure | Base plate, 356 x 356 x 15 mm | Fabricated | 1 | pcs | MDF | Cut and drilled from MDF sheet | Local fabrication | https://www.falabella.com.pe/falabella-pe/product/116632866/Tablero-MDF-15mm-2135x2440mm/116632872 | $5,90 | $5,90 | User-confirmed prototype cost: S/20 total. Converted at 1 USD = 3.3898 PEN.
FAB_STR_002 | Structure | Top plate, 420 x 400 x 3 mm | Fabricated | 1 | pcs | Stainless steel | Laser cut/waterjet cut and drilled | Local fabrication | https://jnaceros.com.pe/productos/planchas-de-acero-inoxidable/ | $44,25 | $44,25 | User-confirmed prototype cost: S/150 total. Converted at 1 USD = 3.3898 PEN.
BUY_ACT_001 | Actuation | NEMA 23 stepper motor JK57HS51-2804 | Purchased | 2 | pcs | Commercial motor | Purchased motor | AliExpress | https://www.aliexpress.com/item/1005001988090618.html | $10,18 | $20,36 | Verified from user screenshot: AliExpress JK57HS51-2804, 57x51 mm, 2.8 A, 1 N.m, shaft 6.35 mm, US$10.18 each; shipping/taxes excluded.
BUY_ACT_002 | Actuation | TR8x8 lead screw, 550 mm | Purchased | 2 | pcs | Steel | Purchased lead screw | AliExpress | https://www.aliexpress.com/item/1005009621851605.html | $19,45 | $38,90 | Verified from user screenshot: AliExpress T8 screw set, pitch 2 mm, lead 8 mm, selected size 550 mm, US$19.45 each/set; shipping/taxes excluded.
BUY_ACT_003 | Actuation | Flexible coupler, 6.35 x 8 mm | Purchased | 2 | pcs | Aluminum | Purchased shaft coupler | Naylamp Mechatronics | https://naylampmechatronics.com/acoples/235-acople-flexible-de-aluminio-d20l25-635x8mm.html | $4,43 | $8,86 | Primary Naylamp price verified: S/15. User AliExpress screenshot shows US$2.03 but selected size is 5 mm to 5 mm, not 6.35 mm to 8 mm; do not use until correct variant is shown.
BUY_ACT_004 | Actuation | T8 lead screw nut, lead 8 mm | Purchased | 2 | pcs | Brass/metal | Purchased lead screw nut | AliExpress | https://www.aliexpress.com/item/1005004052385590.html | $2,00 | $4,00 | Included/assumed from purchased T8 screw set; keep nominal allocation US$2.00 each unless separated from lead-screw set cost.
BUY_ACT_005 | Actuation | TR8 nut block housing | Purchased | 2 | pcs | Delrin/metal | Purchased nut block | Naylamp Mechatronics | https://naylampmechatronics.com/v-slot/496-bloque-tuerca-para-tornillo-de-potencia-d8mm8.html | $3,25 | $6,50 | Verified: Naylamp S/11 each. Converted at 1 USD = 3.3898 PEN. Shipping/taxes excluded.
FAB_ACT_002 | Actuation | NEMA 23 mounting plate | Fabricated | 2 | pcs | ABS | 3D printed/custom fabricated | Local fabrication | https://4tec.pe/servicio-de-impresion-3d/ | $1,48 | $2,96 | User-confirmed prototype cost: S/5 each. Converted at 1 USD = 3.3898 PEN.
BUY_GUI_003 | Guiding | V-wheel kit with bearings | Purchased | 8 | pcs | Polycarbonate wheel + 625RS bearings | Purchased wheel kit | AliExpress - BULK-MAN 3D Official Store | https://www.aliexpress.com/item/1005007108564849.html | $1,67 | $13,38 | Verified from user order screenshot: 10 sets/lote OpenBuilds Delrin POM Dual V-wheel kit with 625ZZ bearings and nuts, total S/56.71. Unit cost = S/5.671 = US$1.67 at 1 USD = 3.3898 PEN; shipping/taxes excluded.
FAB_GUI_001 | Guiding | Gantry plate, 127 x 88 x 3 mm | Fabricated | 4 | pcs | Stainless steel | Laser cut/waterjet cut and drilled | Local fabrication | https://jnaceros.com.pe/productos/planchas-de-acero-inoxidable/ | $14,75 | $59,00 | User-confirmed prototype cost: S/50 each. Dimensions updated from CAD/drawing v60; previously listed as 20 x 80 mm.
FAB_GUI_002 | Guiding | Spacer block | Fabricated | 4 | pcs | ABS, gray | 3D printed | Local fabrication | https://4tec.pe/servicio-de-impresion-3d/ | $1,48 | $5,92 | User-confirmed prototype cost: S/5 each. Converted at 1 USD = 3.3898 PEN.
STD_FAS_001 | Fasteners | Screw, McMaster 90258A232 | Standard hardware | 12 | pcs | Steel/stainless steel | Purchased fastener | McMaster-Carr | https://www.mcmaster.com/90258A232 | $0,19 | $2,33 | Verified from user McMaster screenshot: 90258A232 | US$4.86 per pack of 25 => US$0.1944 each.
STD_FAS_002 | Fasteners | Screw, McMaster 92125A192 | Standard hardware | 8 | pcs | Steel/stainless steel | Purchased fastener | McMaster-Carr | https://www.mcmaster.com/92125A192 | $0,13 | $1,02 | Verified from user McMaster screenshot: 92125A192 | US$12.77 per pack of 100 => US$0.1277 each.
STD_FAS_003 | Fasteners | Hex nut, McMaster 90592A090 | Standard hardware | 8 | pcs | Steel/stainless steel | Purchased fastener | McMaster-Carr | https://www.mcmaster.com/90592A090 | $0,02 | $0,17 | Verified from user McMaster screenshot: 90592A090 | US$2.09 per pack of 100 => US$0.0209 each.
STD_FAS_004 | Fasteners | Socket head screw, McMaster 92290A148 | Standard hardware | 8 | pcs | 316 stainless steel | Purchased fastener | McMaster-Carr | https://www.mcmaster.com/92290A148 | $0,37 | $2,98 | Verified from user McMaster screenshot: 92290A148 | US$18.62 per pack of 50 => US$0.3724 each.
STD_FAS_005 | Fasteners | Shim, McMaster 96945A303 | Standard hardware | 12 | pcs | Steel/stainless steel | Purchased shim | McMaster-Carr | https://www.mcmaster.com/96945A303 | $0,81 | $9,77 | Verified from user McMaster screenshot: 96945A303 | US$8.14 per pack of 10 => US$0.814 each. Actual purchase may require rounding to full packs.
STD_FAS_006 | Fasteners | Hex nut, McMaster 90592A011 | Standard hardware | 50 | pcs | Steel/stainless steel | Purchased fastener | McMaster-Carr | https://www.mcmaster.com/90592A011 | $0,02 | $1,00 | Verified from user McMaster screenshot: 90592A011 | US$2.00 per pack of 100 => US$0.0200 each.
STD_FAS_007 | Fasteners | Thread-forming screw, McMaster 99461A973 | Standard hardware | 10 | pcs | Steel/stainless steel | Purchased fastener | McMaster-Carr | https://www.mcmaster.com/99461A973 | $0,39 | $3,88 | Verified from user McMaster screenshot: 99461A973 | US$9.69 per pack of 25 => US$0.3876 each.
STD_FAS_008 | Fasteners | M5 wheel spacer | Standard hardware | 16 | pcs | Aluminum | Purchased spacer | Naylamp Mechatronics | https://naylampmechatronics.com/accesorios/491-espaciador-de-aluminio-l6p35mm-t8.html | $0,18 | $2,88 | Verified: Naylamp S/0.60 each; OD 8 mm, ID 5.3 mm, length 6.35 mm. Converted at 1 USD = 3.3898 PEN.
STD_FAS_009 | Fasteners | Truss head screw, McMaster 92467A517 | Standard hardware | 8 | pcs | 18-8 stainless steel | Purchased fastener | McMaster-Carr | https://www.mcmaster.com/92467A517 | $0,24 | $1,92 | Verified from user McMaster screenshot: 92467A517 | US$12.01 per pack of 50 => US$0.2402 each.
STD_FAS_010 | Fasteners | Flat head screw, McMaster 92125A208 | Standard hardware | 32 | pcs | 18-8 stainless steel | Purchased fastener | McMaster-Carr | https://www.mcmaster.com/92125A208 | $0,16 | $5,15 | Verified from user McMaster screenshot: 92125A208 | US$16.09 per pack of 100 => US$0.1609 each. Quantity confirmed from CAD.
STD_FAS_011 | Fasteners | M5 T-slot nut for 2020 profile | Standard hardware | 32 | pcs | Steel | Purchased T-slot nut | Naylamp Mechatronics | https://naylampmechatronics.com/v-slot/494-tuerca-en-t-m5-simple.html | $0,12 | $3,84 | Verified: Naylamp S/0.40 each. Quantity confirmed from CAD. Converted at 1 USD = 3.3898 PEN.
STD_FAS_012 | Fasteners | Pan head screw, McMaster 92000A220 | Standard hardware | 12 | pcs | 18-8 stainless steel | Purchased fastener | McMaster-Carr | https://www.mcmaster.com/92000A220 | $0,12 | $1,40 | Verified from user McMaster screenshot: 92000A220 | US$11.65 per pack of 100 => US$0.1165 each.
STD_FAS_013 | Fasteners | Thread-forming screw, McMaster 99461A971 | Standard hardware | 4 | pcs | Steel/stainless steel | Purchased fastener | McMaster-Carr | https://www.mcmaster.com/99461A971 | $0,29 | $1,17 | Verified from user McMaster screenshot: 99461A971 | US$7.31 per pack of 25 => US$0.2924 each.
BUY_ELE_001 | Electronics | Raspberry Pi 5 single-board computer, 8 GB RAM | Purchased | 1 | pcs | Commercial PCB assembly | Purchased SBC | AliExpress / Raspberry Pi supplier | https://www.aliexpress.com/wholesale?SearchText=Raspberry+Pi+5+8GB | $125,00 | $125,00 | Pending exact AliExpress seller/product screenshot. Unit cost kept as product-only estimate until selected item is confirmed.
BUY_ELE_002 | Electronics | MCP2515 CAN-SPI module | Purchased | 1 | pcs | Commercial PCB assembly | Purchased CAN interface module | AliExpress | https://www.aliexpress.com/item/1005010485202979.html | $2,55 | $2,55 | Verified from user screenshot/link: MCP2515 CAN Bus Driver Module Board TJA1050 Receiver SPI; US$2.55 each; shipping/taxes excluded.
BUY_ELE_003 | Electronics | TB6600 stepper motor driver module | Purchased | 2 | pcs | Commercial electronic module | Purchased stepper driver | AliExpress - FANGXIN Store | https://www.aliexpress.com/item/1005010711593232.html | $18,85 | $37,70 | Verified from user screenshot/link: TB6600 stepper driver 4.0A 42VDC | selected 2PCS pack at US$37.70; unit cost = US$18.85; shipping/taxes excluded.
 |  |  |  |  |  |  |  |  |  | Estimated total | $484,78 | Product/material cost only. Updated exact AliExpress links for MCP2515 and TB6600; shipping/customs/taxes excluded. Raspberry Pi exact seller still pending.

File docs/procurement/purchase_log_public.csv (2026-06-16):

ID | Date | Supplier | Item_or_description | Qty_or_option | Amount_PEN | Target_area | HardwareX_status | BOM_linkage | Evidence_source | Public_notes
PRC-001 | 2025-05-12 | Devota Store / AliExpress | Worm gear set: copper turbine gear with stainless-steel worm shaft | AWorm-8mm, 50 teeth-8mm | 82.45 | Arm mechanics | Active / reconcile cost | BOM-001 candidate | Orders.pdf page 1 | BOM currently records a different cost; reconcile before final BOM freeze.
PRC-002 | 2025-05-12 | Tootootool Store / AliExpress | Flexible aluminum shaft coupling | 2 pcs 8-8mm; order qty 5 | 29.8 | Arm/elevator mechanics | Active / reconcile quantity | BOM-007 candidate | Orders.pdf page 1 | Quantity/cost differs from current BOM line; reconcile.
PRC-003 | 2025-05-12 | Baiozraw 2th Store / AliExpress | T8 screw kit / vertical or horizontal lead screw | KFL08, 550mm | 60.52 | Elevator mechanics | Active | BOM-033 related | Orders.pdf page 1 | Elevator screw/lead support evidence.
PRC-004 | 2025-05-12 | Shop911413572 Store / AliExpress | 688ZZ ball bearings | 10 pcs, 8x16x5mm | 8.12 | Arm mechanics | Active / to classify | New or BOM-006 related | Orders.pdf page 1 | Bearing size differs from 6810/AXK lines; classify in final BOM.
PRC-005 | 2025-05-12 | TOP-Choice Store / AliExpress | ACS712 current sensor modules | 4 pcs, 5A | 14.22 | Electronics | Active | BOM-005 related | Orders.pdf page 1 | Current sensing evidence.
PRC-006 | 2025-05-12 | Super 1 Store / AliExpress | Stainless steel rod 304 | 500mm, 8mm, 1 pc | 29.53 | Arm/elevator mechanics | Active / to classify | New or BOM-003 related | Orders.pdf pages 1-2 | Classify against shaft/rod line.
PRC-007 | 2025-04-24 | 3C Computer Peripheral Store / AliExpress | ESP32 development board | 30-pin Type-C | 16.52 | Electronics / firmware nodes | Active | BOM-019 related | Orders.pdf page 2 | ESP32 node evidence.
PRC-008 | 2025-04-24 | HuiShengDongye Store / AliExpress | LM2596S buck converter, DC-DC 24V/12V to 5V 5A | 1 unit | 6.41 | Power electronics | Active | BOM-020 related | Orders.pdf page 2 | Matches documented 5V logic rail converter.
PRC-009 | 2025-04-24 | EXinko Electronics Store / AliExpress | DRV8825 stepper-driver modules | 5 pcs DRV8825 | 20.85 | Legacy electronics | Legacy / removed from active design | Legacy, not final BOM | Orders.pdf page 2 | Not part of current public HardwareX active design; retained as historical purchase.
PRC-010 | 2025-04-24 | Baiozraw 2th Store / AliExpress | T8 screw kit / lead screw support | 550mm, KP08 | 63.42 | Elevator mechanics | Active / to reconcile | BOM-033 related | Orders.pdf page 2 | May overlap with other T8/KFL08 order; reconcile final quantity.
PRC-011 | 2025-04-24 | SOREKARA PRO / AliExpress | AXK thrust needle bearing | 40x60x3mm, 1 pc | 3.89 | Arm/elevator mechanics | Active / to classify | BOM-016 related | Orders.pdf page 2 | AXK bearing evidence.
PRC-012 | 2025-04-24 | Shop1103886172 Store / AliExpress | Thin-wall deep-groove ball bearings | 6810 ZZ, 50x65x7mm, 2 pcs | 26.74 | Arm/elevator mechanics | Active | BOM-015 related | Orders.pdf page 2 | Bearing evidence.
PRC-013 | 2025-04-24 | BULK-MAN 3D Official Store / AliExpress | OpenBuilds Dual V wheel kit | 625ZZ Nut, 10 sets | 56.71 | Elevator mechanics | Active / reconcile cost | BOM-035 related | Orders.pdf page 3 | Current BOM cost differs; reconcile.
PRC-014 | 2025-04-24 | TriArk Electronic Components Store / AliExpress | PC817C optocouplers | 20 pcs | 3.6 | Electronics | Active | BOM-018 related | Orders.pdf page 3 | Optocoupler evidence.
PRC-015 | 2025-04-24 | CAG 222 Store / AliExpress | DRV8871 brushed DC motor-driver breakout boards | 5 pcs | 70.61 | Electronics / arm drivers | Active / reconcile cost | BOM-014 related | Orders.pdf page 3 | Current design uses DRV8871 for J1/J4; cost/qty to reconcile.
PRC-016 | 2025-06-17 | tai heng | Tape/marker for sensor fabrication | 1 expense line | 13.15 | Validation / fabrication | To review | New / tooling | Liquidacion gastos 31-03-2025 | Classify as consumable or validation material.
PRC-017 | 2025-06-17 | led electrical solutions SAC | Duraflex cable tie / strap | 1 expense line | 7.0 | Cable management | Active / consumable | New / consumable | Liquidacion gastos 31-03-2025 | Cable management consumable.
PRC-018 | 2025-06-17 | Inthectronics | CNY70 IR sensor and BTS7960 H-bridge | 1 expense line | 144.0 | Legacy electronics / sensors | To review / partially legacy | Legacy BTS7960 | Liquidacion gastos 31-03-2025 | BTS7960 not current final driver; CNY70 status unclear.
PRC-019 | 2025-05-10 | SODIMAC | Nails, sandpaper, screws and adhesives | 1 expense line | 51.11 | Fabrication consumables | Active / consumable | New / consumable | Liquidacion gastos 31-03-2025 | Consumables; not necessarily installed BOM.
PRC-020 | 2025-05-10 | SODIMAC | Hand saw | 1 expense line | 26.9 | Tooling | Tool / not installed | Tooling | Liquidacion gastos 31-03-2025 | Tool, not installed component.
PRC-021 | 2025-05-03 | SAWERS | TB6600 driver + NEMA23 motor | 1 expense line | 140.0 | Elevator actuator | Active | BOM-034/BOM-038 related | Liquidacion gastos 31-03-2025 | Elevator driver/motor evidence.
PRC-022 | 2025-05-28 | DELFIN PERNOS | Bolts, washers and screws | 1 expense line | 53.8 | Mechanical fasteners | Active / fasteners | Fasteners table pending | Liquidacion gastos 31-03-2025 | Use in hardware/fasteners later.
PRC-023 | 2025-06-26 | SAISAC MECHATRONICS | V-slot 2020 90-degree corner bracket + 6mm rigid flange coupling | 1 expense line | 50.0 | Elevator/mechanical structure | Active | Hardware/fasteners pending | Liquidacion gastos 31-03-2025 | Mechanical connection hardware.
PRC-024 | 2025-05-28 | DUCASSE COMERCIAL | 61810-2RS deep-groove ball bearing | 1 expense line | 51.68 | Arm/elevator mechanics | Active / to classify | BOM-015 related | Liquidacion gastos 31-03-2025 | Bearing evidence; verify exact dimensions.
PRC-025 | 2025-05-10 | SODIMAC | Melamine 18mm + screws + PVC tube | 1 expense line | 84.18 | Prototype structure | To review | BOM-004 related | Liquidacion gastos 31-03-2025 | May be tooling/prototype support rather than final installed part.
PRC-026 | 2025-05-17 | SAWERS | TB6600 driver, NEMA23, ACS sensors, passive components | 1 expense line | 206.0 | Elevator + electronics | Active | BOM-005/BOM-034/BOM-038 related | Liquidacion gastos 31-03-2025 | Bundle purchase; split by item if invoices are reviewed.
PRC-027 | 2025-06-25 | ELECTRONICA HI FI | MCP2515 CAN 2.0B module, 5V operation, SPI interface | 1 expense line | 26.0 | CAN interface | Active | MCP2515 evidence | Liquidacion gastos 31-03-2025 | Confirms 5V MCP2515 module detail.
PRC-028 | 2025-05-21 | NAYLAMP MECHATRONICS | MCP2515 module + male header 11mm + shipping | 1 expense line | 41.0 | CAN interface | Active | MCP2515 evidence | Liquidacion gastos 31-03-2025 | MCP2515 local purchase evidence.
PRC-029 | 2025-04-25 | Micro DC Motors | DC motors NFP-5840-31ZY-EN and NFP-36GP-555-EN | Bundle | 375.666 | Arm actuators | Active | BOM-011/BOM-012/BOM-013 related | Liquidacion gastos 31-03-2025 | Bundle includes motors/shipping; reconcile split vs BOM.
PRC-030 | 2025-10-20 | SAI SAC MECATRONICA | V-Slot 2020 profiles 70cm x4 and 35cm x2 | 1 expense line | 157.5 | Mechanical structure | Active / to reconcile | Hardware/cad/fasteners pending | Tarjeta corporativa liquidation | Likely arm/elevator frame material.
PRC-031 | 2025-10-30 | SAI SAC MECATRONICA | KP-08 bearing blocks, 6x6 couplings, V-slot 90 brackets, M5 screws and T-nuts | 1 expense line | 112.0 | Mechanical structure | Active / fasteners | Hardware/fasteners pending | Tarjeta corporativa liquidation | Good source for fastener table.
PRC-032 | 2025-10-30 | SAI SAC MECATRONICA | 6mm belt kit, V-slot system, motor pulley, idler pulley, M5x25 screw, spacer, anti-backlash nut, NEMA17, A4988 | 1 expense line | 145.0 | Prototype mechanism | To review / partially legacy | Legacy A4988/NEMA17? | Tarjeta corporativa liquidation | May belong to test rig or non-final mechanism; clarify before active BOM.
PRC-033 | 2025-11-07 | SAI SAC MECATRONICA | V-slot 90-degree brackets x10 and universal double L brackets x10 | 1 expense line | 75.0 | Mechanical structure | Active / fasteners | Hardware/fasteners pending | Tarjeta corporativa liquidation | Use in fasteners/hardware table.
PRC-034 | 2025-11-11 | SODIMAC | Threaded rod 3/16 x1m and hex nuts 3/16 box x100 | 1 expense line | 19.8 | Mechanical fasteners | Active / fasteners | Hardware/fasteners pending | Tarjeta corporativa liquidation | Use in fasteners table if used in final build.
PRC-035 | 2025-11-19 | Electronica INDUTECH S.A.C. | BTS7960 H-bridge driver | 1 expense line | 50.0 | Legacy electronics | Legacy / removed from active design | Not active BOM | Tarjeta corporativa liquidation | BTS7960 not final current driver.
PRC-036 | 2025-11-27 | GRUPO JR SERVICIOS Y FABRICACIONES S.A.C. | Metal part fabrication | 1 expense line | 100.0 | Mechanical fabrication | Active / to classify | Hardware drawings pending | Tarjeta corporativa liquidation | Need identify part and link to CAD/drawing.
PRC-037 | 2025-11-28 | MEDIAWORD STORE | ESP32 and electronic circuit board | 1 expense line | 54.5 | Electronics / firmware nodes | Active / to reconcile | BOM-019 related | Tarjeta corporativa liquidation | Local ESP32/electronics evidence.
PRC-038 | 2025-12-03 | SAI SAC MECATRONICA | BTS7960 H-bridge driver | 1 expense line | 38.0 | Legacy electronics | Legacy / removed from active design | Not active BOM | Tarjeta corporativa liquidation | BTS7960 not final current driver.
PRC-039 | 2025-11-01 | Unspecified / no receipt section | Audio acquisition interface for prototype | 1 expense line | 60.0 | Prototype auxiliary electronics | Out of current scope / to review | Not active BOM | Tarjeta corporativa liquidation | Likely outside current arm/elevator HardwareX scope; clarify.

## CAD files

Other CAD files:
hardware/step/ASM_Elevator_System_v60.step
hardware/drawings/FAB_STR_002_Top_Plate_420x400x3_StainlessSteel_v60.dxf
hardware/stl/FAB_GUI_002_Spacer_Block_ABS_Gray_v60.stl
hardware/drawings/FAB_GUI_001_Gantry_Plate_127x88x3_StainlessSteel_v60.dxf
hardware/stl/FAB_ACT_002_NEMA23_Mounting_Plate_ABS_v60.stl
hardware/cad/complete_robot/ASM_Elevator_System_v60.f3z

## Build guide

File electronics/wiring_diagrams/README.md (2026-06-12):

# Diagramas de cableado

Colocar aqui diagramas practicos de cableado para ensamblar el robot.

Diagramas recomendados:

- cableado completo del robot
- cableado del bus CAN
- cableado del nodo motor J1
- cableado del nodo motor J2
- cableado del nodo motor J3
- cableado del nodo motor J4
- cableado del elevador J5
- cableado del gripper o efector final

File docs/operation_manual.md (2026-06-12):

# Manual de operación

Este manual describe la secuencia básica para compilar, ejecutar y probar el sistema desde ROS 2.

## Requisitos

- Ubuntu con ROS 2 Jazzy instalado.
- Workspace del proyecto en `~/robot-project/ros2_ws`.
- Interfaz CAN física `can0` o interfaz virtual `vcan` para pruebas sin hardware.
- ESP-IDF instalado fuera del repositorio para programar los ESP32.

## Compilación de ROS 2

```bash
cd ~/robot-project/ros2_ws
source /opt/ros/jazzy/setup.bash
rm -rf build install log
colcon build --packages-select can_comm_pkg
source install/setup.bash
```

## Prueba sin hardware usando CAN virtual

```bash
sudo modprobe vcan
sudo ip link add dev can0 type vcan 2>/dev/null || true
sudo ip link set up can0
ip link show can0
```

Iniciar el nodo CAN:

```bash
ros2 run can_comm_pkg can_node
```

Salida esperada:

```text
CANNode iniciado y suscrito a /can_command
```

## Prueba con CAN físico

Cuando esté conectada la interfaz CAN física:

```bash
sudo ip link set can0 down 2>/dev/null || true
sudo ip link set can0 up type can bitrate 500000
ip -details link show can0
candump can0
```

En otra terminal:

```bash
cd ~/robot-project/ros2_ws
source install/setup.bash
ros2 run can_comm_pkg can_node
```

## Comandos principales

| Comando | Uso |
|---|---|
| `ros2 run can_comm_pkg can_node` | Inicia el puente ROS 2 / SocketCAN. |
| `ros2 run can_comm_pkg control_teclado` | Control por teclado. |
| `ros2 run can_comm_pkg can_traj` | Ejecuta trayectoria desde ROS 2. |
| `ros2 run can_comm_pkg can_slider` | Control por sliders. |
| `ros2 run can_comm_pkg ik_node` | Nodo de cinemática inversa. |
| `ros2 run can_comm_pkg j5_ramp` | Prueba del elevador J5 con perfil rampa. |
| `ros2 run can_comm_pkg j5_trap` | Prueba del elevador J5 con perfil trapezoidal. |

## Programación de firmware ESP32

Cargar ESP-IDF:

```bash
source /media/F15/Data/ESP_IDF_CONTAINER/v5.3.3/esp-idf/export.sh
```

Compilar un nodo, por ejemplo J1:

```bash
cd ~/robot-project/firmware/esp32_joint_node/J1
idf.py set-target esp32
idf.py build
```

Flashear cuando el ESP32 esté conectado:

```bash
idf.py -p /dev/ttyUSB0 flash monitor
```

## Secuencia de encendido recomendada

1. Verificar cableado de potencia y tierra común.
2. Verificar terminaciones CAN de 120 ohmios en los extremos del bus.
3. Encender alimentación lógica.
4. Encender alimentación de actuadores.
5. Levantar `can0`.
6. Ejecutar `can_node`.
7. Ejecutar el comando de control o prueba.

## Secuencia de apagado recomendada

1. Detener comandos ROS 2 activos.
2. Detener `can_node`.
3. Apagar alimentación de actuadores.
4. Apagar alimentación lógica.
5. Desconectar alimentación principal si se trabaja sobre el cableado.

## Parada o incidencia

Si el movimiento no es esperado:

- detener el proceso ROS 2 con `Ctrl+C`;
- cortar alimentación de actuadores;
- revisar CANH/CANL;
- revisar tierra común;
- revisar IDs CAN;
- revisar alimentación del nodo ESP32 correspondiente.

## Documentos relacionados

- `docs/ros2_entrypoints_validation.md`
- `docs/troubleshooting.md`
- `firmware/ESP_IDF_BUILD_GUIDE.md`
- `electronics/pinout_tables/esp32_pinout_table.md`

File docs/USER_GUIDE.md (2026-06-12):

# User Guide

## 🎮 Teleoperation

Control the robot using the keyboard.

```bash
ros2 run can_comm_pkg control_teclado
```

*   **Keys**:
    *   `1`/`Q`: J1 +/-
    *   `2`/`W`: J2 +/-
    *   `3`/`E`: J3 +/-
    *   `4`/`R`: J4 +/-
    *   `5`/`T`: J5 +/-

## 📈 Trajectory Generation

Launch the GUI to design and execute trajectories.

```bash
ros2 run can_comm_pkg can_traj
```

1.  **Home**: Moves robot to zero position.
2.  **Add Point**: Adds current configuration to trajectory.
3.  **Generate**: Creates a smooth path (LSPB/Trapezoidal).
4.  **Execute**: Sends commands to the robot.

## 🧪 Performance Testing

Run automated tests to verify joint performance.

**Syntax:**
```bash
ros2 run can_comm_pkg j<JOINT>_<PROFILE>
```

**Available Tests:**
*   **Joints**: `j1`, `j2`, `j3`, `j4`, `j5`
*   **Profiles**: `step`, `ramp`, `trap`

**Example:**
```bash
ros2 run can_comm_pkg j5_step
```
*   Prompts for Target (mm) and Time.
*   Executes 5 repetitions.
*   Saves data and plots to `resultados/`.

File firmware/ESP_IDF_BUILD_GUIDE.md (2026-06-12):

# Guia de compilacion ESP-IDF

Esta guia define como debe quedar el firmware para que, al descargar el repositorio, se pueda compilar y programar cada ESP32 desde la rama `hardwarex-publication-package`.

## Recomendacion sobre ESP-IDF

No subir ESP-IDF completo al repositorio. ESP-IDF, sus herramientas, toolchains y contenedores pueden pesar varios GB y son dependencias externas. En GitHub solo debe ir el codigo fuente del proyecto del robot.

Mantener ESP-IDF instalado fuera del repositorio, por ejemplo en:

```text
/media/F15/Data/ESP_IDF_CONTAINER/
/media/F15/Data/ESP_IDF_TOOLS/
```

El repositorio debe ser reproducible indicando como cargar o instalar ESP-IDF, no copiando ESP-IDF dentro del repo.

## Estado actual

El firmware fue recuperado desde los ZIP subidos al chat:

- `JointPosition y JointVelocity Controllers.zip`
- `can-controll-.zip`

Ya se documentaron los pines y se subieron archivos clave de configuracion por nodo. Para dejar cada proyecto completamente compilable, deben estar presentes tambien los archivos fuente restantes de J1 a J4.

## Estructura objetivo

```text
firmware/
├── esp32_joint_node/
│   ├── J1/
│   │   ├── CMakeLists.txt
│   │   └── main/
│   │       ├── CMakeLists.txt
│   │       ├── main.c
│   │       ├── base_libs.h
│   │       ├── node_config.h
│   │       ├── encoder_driver.h
│   │       ├── motor_driver.h
│   │       ├── pid_controller.h
│   │       └── twai_comms.h
│   ├── J2/
│   ├── J3/
│   └── J4/
│       └── main/
│           └── grip_controller.h
└── esp32_stepper_node/
    └── J5_tb6600/
        ├── CMakeLists.txt
        └── main/
            ├── CMakeLists.txt
            ├── Kconfig.projbuild
            └── twai_network_example_slave_main.c
```

## Archivos que no deben subirse

No versionar:

```text
build/
.vscode/
.devcontainer/
sdkconfig.old
.clangd
*.bin
*.elf
*.map
ESP_IDF_CONTAINER/
ESP_IDF_TOOLS/
esp-idf/
.espressif/
```

## Si aparece `idf.py: command not found`

Ese error significa que ESP-IDF no esta cargado en esa terminal o no esta instalado.

Primero buscar el archivo `export.sh` de ESP-IDF:

```bash
find "$HOME" /media/F15/Data -type f -path "*/esp-idf/export.sh" 2>/dev/null
```

Si aparece una ruta, cargarla. Ejemplo segun la instalacion actual del proyecto:

```bash
source /home/f15/projects/tb6600_can_control_vscode/components/ESP_IDF_CONTAINER/v5.3.3/esp-idf/export.sh
```

Si ESP-IDF esta en el disco externo, usar la ruta real que devuelva el comando `find`, por ejemplo:

```bash
source /media/F15/Data/ESP_IDF_CONTAINER/v5.3.3/esp-idf/export.sh
```

Despues verificar:

```bash
idf.py --version
echo $IDF_PATH
ls "$IDF_PATH/tools/cmake/project.cmake"
```

Para no repetirlo en cada terminal, agregarlo a `.bashrc` usando la ruta real encontrada:

```bash
echo 'source /media/F15/Data/ESP_IDF_CONTAINER/v5.3.3/esp-idf/export.sh' >> ~/.bashrc
source ~/.bashrc
```

Solo usar esa linea si la ruta existe en tu equipo.

Si no existe ningun `export.sh`, instalar ESP-IDF:

```bash
mkdir -p ~/esp
cd ~/esp
git clone -b v5.3.2 --recursive https://github.com/espressif/esp-idf.git
cd esp-idf
./install.sh esp32
source ./export.sh
idf.py --version
```

Con VS Code tambien se puede instalar desde la extension Espressif IDF:

1. Abrir VS Code.
2. Instalar extension `Espressif IDF`.
3. Ejecutar `ESP-IDF: Configure ESP-IDF Extension`.
4. Usar `Express` setup o apuntar a la ruta existente en el disco externo.
5. Abrir la carpeta de un nodo, por ejemplo `firmware/esp32_joint_node/J1`.
6. Usar `ESP-IDF: Build`, `ESP-IDF: Flash` y `ESP-IDF: Monitor`.

## Compilar un nodo J1-J4

Ejemplo para J1:

```bash
cd firmware/esp32_joint_node/J1
idf.py set-target esp32
idf.py build
idf.py -p /dev/ttyUSB0 flash monitor
```

Cambiar `J1` por `J2`, `J3` o `J4` segun el ESP32 que se desea programar.

## Compilar el elevador J5

```bash
cd firmware/esp32_stepper_node/J5_tb6600
idf.py set-target esp32
idf.py build
idf.py -p /dev/ttyUSB0 flash monitor
```

## Verificar puerto serie

```bash
ls /dev/ttyUSB*
ls /dev/ttyACM*
```

En Linux, si no aparece el puerto o no hay permisos:

```bash
sudo usermod -aG dialout $USER
```

Cerrar sesion y volver a entrar.

## Relacion con ROS 2

- ROS 2 queda en `ros2_ws/`.
- Los ESP32 se programan desde `firmware/`.
- ESP-IDF queda fuera del repositorio como dependencia externa.
- La comunicacion entre ROS 2 y ESP32 se realiza mediante CAN/TWAI a 500 kbit/s.
- La Raspberry Pi usa MCP2515 como interfaz CAN.

## Pendiente

- Subir todos los archivos fuente restantes de J1-J4 para que cada carpeta compile de forma autonoma.
- Confirmar formato final de payload CAN entre ROS 2 y ESP32.
- Confirmar si J5 queda como `J5_tb6600` o si se conservara tambien una version historica `J5_twai_id_based`.

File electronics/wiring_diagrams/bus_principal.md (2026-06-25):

<!-- SPDX-License-Identifier: CERN-OHL-S-2.0 -->

# Main bus wiring diagram

This document describes the main power and CAN bus of the Assistbelle robotic arm and elevator subsystem based on the reviewed `Main Bus.pdf` schematic and current user-confirmed design intent.

## Source schematic

| File | Description | Status |
|---|---|---|
| [`../schematics/Main Bus.pdf`](../schematics/Main%20Bus.pdf) | Main 12 V / 5 V / CAN distribution bus. | Reviewed from PDF; physical implementation still pending. |

## Bus lines

The main bus distributes power and communication through six labeled lines.

| Line | Function | Domain | Notes |
|---|---|---|---|
| `12V` | Actuator power rail. | Power | Feeds motor drivers and actuator-side loads. Interrupted by the panic button according to current design intent. |
| `P_GND` | Power ground. | Power | Return path for actuator/motor power. |
| `5V` | Logic power rail. | Signal / logic | Feeds Raspberry Pi, ESP32 nodes and CAN-related logic. Remains powered during panic-button activation according to current design intent. |
| `S_GND` | Signal ground. | Signal / logic | Reference for logic, CAN transceivers and telemetry electronics. |
| `CANH` | CAN high differential line. | Communication | Pair with CANL. |
| `CANL` | CAN low differential line. | Communication | Pair with CANH. |

The current documentation treats `P_GND` and `S_GND` as separated domains. Their final physical bonding or isolation strategy must be verified on the robot.

## Connector groups from `Main Bus.pdf`

| Group | Schematic connector | Pin count | Signals | Purpose | Verification status |
|---|---|---:|---|---|---|
| `POWER_SUPPLIES` | `12V_PSU` | 2 | `12V`, `P_GND` | Main actuator-supply input. | Wiring and Dell PSU model pending. |
| `POWER_SUPPLIES` | `5V_PSU` | 2 | `5V`, `S_GND` | Logic-supply input from DC-DC converter. | Wiring and converter placement pending. |
| `RPI_CONNECTIONS` | `MCP_2515` | 2 | `CANH`, `CANL` | CAN branch to the Raspberry Pi/MCP2515 interface. | Pin order pending. |
| `RPI_CONNECTIONS` | `RPI_POWER` | 2 | `5V`, `S_GND` | Logic power branch for Raspberry Pi side. | Current design intent: remains powered during panic-button activation. |
| `DC_MOTOR_CONTROLLER_X4` | `DCM_MOTOR_POWER` | 2 | `12V`, `P_GND` | Actuator power for four DC motor-controller branches. | Current design intent: interrupted by panic button. |
| `DC_MOTOR_CONTROLLER_X4` | `DCM_LOGIC_POWER` | 2 | `5V`, `S_GND` | Logic power for DC motor-controller nodes. | Current design intent: remains powered during panic-button activation. |
| `DC_MOTOR_CONTROLLER_X4` | `DCM_CAN_SN65H` | 2 | `CANH`, `CANL` | CAN branch for DC motor-controller transceivers. | Physical branching pending. |
| `STEPPER_MOTOR_CONTROLLER` | `STPR_LOGIC_POWER` | 2 | `5V`, `S_GND` | Logic power for the J5/elevator controller. | Current design intent: remains powered during panic-button activation. |
| `STEPPER_MOTOR_CONTROLLER` | `STPR_CAN_SN65H` | 2 | `CANH`, `CANL` | CAN branch for the J5/elevator controller. | Physical wiring pending. |

## CAN termination

The reviewed schematic shows two 120-ohm CAN termination resistors:

| Reference | Value | Location in schematic | Physical status |
|---|---:|---|---|
| `RT1` | 120 ohm | One end of the CAN bus, between `CANH` and `CANL`. | Planned by design; physical location to verify. |
| `RT2` | 120 ohm | Opposite end of the CAN bus, between `CANH` and `CANL`. | Planned by design; physical location to verify. |

Implementation rule:

- place one 120-ohm termination between `CANH` and `CANL` at the beginning of the bus;
- place one 120-ohm termination between `CANH` and `CANL` at the end of the bus;
- avoid additional intermediate terminations on branch nodes unless the physical bus topology requires a documented change.

## J5 dual-driver design intent

The elevator uses two TB6600 stepper drivers for two NEMA 23 motors. The current user-confirmed design intent is that both TB6600 drivers receive the same ESP32 control signals in parallel:

| ESP32 signal | GPIO | Destination |
|---|---:|---|
| `PUL` | GPIO5 | TB6600 Motor A `PUL` and TB6600 Motor B `PUL` |
| `DIR` | GPIO18 | TB6600 Motor A `DIR` and TB6600 Motor B `DIR` |
| `ENA` | GPIO19 | TB6600 Motor A `ENA` and TB6600 Motor B `ENA` |

The supply voltage used by the two TB6600 drivers is still pending physical inspection.

## Relationship with the current power architecture

The current hardware notes define:

| Block | Current documented implementation |
|---|---|
| Main actuator supply | Dell server power supply, 12 V, 1 kW, 88 A, exact model pending. |
| Logic supply | LM2596S DC-DC buck converter, 24 V / 12 V input to 5 V, 5 A output. |
| Emergency / panic button | Cuts actuator power while Raspberry Pi, ESP32 nodes and CAN/telemetry remain powered. |
| Grounds | `P_GND` and `S_GND` documented as separated domains. |

The panic-button wiring path is not shown explicitly in `Main Bus.pdf`; it must be documented with a photo or updated schematic before final publication.

## Recommended wiring notes

These notes should be verified against the physical implementation:

- use higher-current wiring for `12V` and `P_GND` actuator branches;
- use logic-rated wiring for `5V` and `S_GND` branches;
- use a twisted pair for `CANH` and `CANL`;
- keep CAN stubs as short as practical;
- label `CANH` and `CANL` consistently across every connector;
- keep connector orientation visible in the final photos.

## Physical verification checklist

- [ ] Photograph the full main bus wiring.
- [ ] Photograph the Dell server power-supply connection to `12V_PSU`.
- [ ] Photograph the LM2596S output wiring to `5V_PSU`.
- [ ] Confirm the supply voltage used by both J5 TB6600 drivers.
- [ ] Confirm the exact physical location of `RT1`.
- [ ] Confirm the exact physical location of `RT2`.
- [ ] Verify that `CANH` and `CANL` are not swapped in any branch.
- [ ] Confirm whether `P_GND` and `S_GND` remain separated or are bonded at one defined point.
- [ ] Document the panic-button actuator-power cut-off path.
- [ ] Update [`connector_table.md`](connector_table.md) with connector model, pin order, wire color and cable gauge.

## Related documents

- [`../schematics/schematics_index.md`](../schematics/schematics_index.md)
- [`connector_table.md`](connector_table.md)
- [`nodos_controladores.md`](nodos_controladores.md)
- [`../power_distribution/power_summary.md`](../power_distribution/power_summary.md)
- [`../images/README.md`](../images/README.md)

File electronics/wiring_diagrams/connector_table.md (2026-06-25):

<!-- SPDX-License-Identifier: CERN-OHL-S-2.0 -->

# Connector table

This file is the working connector table for the Assistbelle robotic arm and elevator subsystem. It combines information extracted from the schematic PDFs, repository documentation, firmware-derived pinout tables and user-confirmed design intent. Fields that require inspection of the physical robot remain explicitly marked as deferred or to verify.

## Status legend

| Mark | Meaning |
|---|---|
| Known from schematic | Value extracted from the uploaded schematic PDFs. |
| Known from docs | Value taken from repository documentation or firmware-derived pinout tables. |
| User-confirmed design intent | Confirmed by the project owner as intended architecture; physical wiring may still need verification. |
| Deferred physical verification | Must be checked when the physical robot is accessible again. |
| Unknown | Value is not available yet and must be filled from inspection, photos or measurements. |

## User-confirmed design decisions

| Topic | Confirmed decision | Remaining verification |
|---|---|---|
| J5 dual TB6600 control | The two TB6600 drivers receive the same `PUL`, `DIR` and `ENA` signals in parallel so the two NEMA 23 motors move synchronously. | Confirm physical wiring and terminal order. |
| J5 TB6600 actuator supply | Supply voltage still pending physical inspection. | Confirm whether both TB6600 drivers are powered from the Dell 12 V PSU or another rail. |
| MCP2515 power | MCP2515 module is powered from 5 V. | Confirm exact module model and 3.3 V SPI/INT compatibility with Raspberry Pi. |
| Emergency / panic button | Panic button cuts only actuator-side 12 V power; Raspberry Pi, ESP32 nodes and 5 V logic remain powered. | Photograph final panic-button wiring path. |
| CAN termination | RT1 and RT2 are intended as 120-ohm terminations at the two physical ends of the CAN bus. | Confirm physical resistor locations. |

## Main bus connector inventory

Extracted from `Main Bus.pdf`.

| Connector ID | Schematic connector | Subsystem | Pin count | Signals | Status | Notes |
|---|---|---|---:|---|---|---|
| C-MBUS-12V-IN | `12V_PSU` | Power supplies | 2 | 12V, P_GND | Known from schematic; deferred physical verification | Input from Dell server PSU. Exact PSU model and final wiring photo pending. |
| C-MBUS-5V-IN | `5V_PSU` | Power supplies | 2 | 5V, S_GND | Known from schematic; deferred physical verification | Input from LM2596S 5 V logic rail. |
| C-MBUS-RPI-CAN | `MCP_2515` | Raspberry Pi connections | 2 | CANH, CANL | Known from schematic; deferred physical verification | Branch to MCP2515 CAN module. |
| C-MBUS-RPI-PWR | `RPI_POWER` | Raspberry Pi connections | 2 | 5V, S_GND | Known from schematic and design intent | Logic power branch to Raspberry Pi; remains powered during emergency stop. |
| C-MBUS-DCM-PWR | `DCM_MOTOR_POWER` | DC motor controller x4 | 2 | 12V, P_GND | Known from schematic; deferred physical verification | Actuator power branch for DC motor controllers; interrupted by panic button by design. |
| C-MBUS-DCM-LOGIC | `DCM_LOGIC_POWER` | DC motor controller x4 | 2 | 5V, S_GND | Known from schematic and design intent | Logic power branch for DC motor controllers; remains powered during emergency stop. |
| C-MBUS-DCM-CAN | `DCM_CAN_SN65H` | DC motor controller x4 | 2 | CANH, CANL | Known from schematic; deferred physical verification | CAN branch for DC motor-controller CAN transceiver. |
| C-MBUS-STPR-LOGIC | `STPR_LOGIC_POWER` | Stepper motor controller | 2 | 5V, S_GND | Known from schematic and design intent | Logic power branch for J5/elevator controller; remains powered during emergency stop. |
| C-MBUS-STPR-CAN | `STPR_CAN_SN65H` | Stepper motor controller | 2 | CANH, CANL | Known from schematic; deferred physical verification | CAN branch for J5/elevator controller. |

Main Bus also shows two 120-ohm CAN terminations: `RT1` and `RT2`. They are intended to be placed at the two physical ends of the CAN bus; exact physical locations remain deferred until robot access.

## Raspberry Pi to MCP2515 connector inventory

Extracted from `RASPBERRYPI_MCP2515.pdf` and updated with the confirmed implementation note that the MCP2515 module is powered from 5 V.

| Connector ID | Schematic connector | Subsystem | Pin count | Signals | Status | Notes |
|---|---|---|---:|---|---|---|
| C-RPI-GPIO | `J_RPI` | Raspberry Pi GPIO | 40 | 3V3, 5V, GND, MOSI, MISO, SCK, CS_CAN, INT_CAN | Known from schematic, wiring to verify | Raspberry Pi 40-pin header. SPI/INT signals must remain Raspberry Pi 3.3 V logic-compatible. |
| C-MCP-HEADER | `J_MCP` | MCP2515 module | 10 | 3V3, GND, SCK, MOSI, MISO, CS_CAN, NC, INT_CAN, CANL, CANH | Known from schematic, logic compatibility to verify | Schematic shows a 3V3 reference at the MCP header; final module power is 5 V through `J_POWER`. |
| C-MCP-CAN | `J_CAN` | CAN connector | 2 | CANH, CANL | Known from schematic, pin order to verify | CAN output from MCP2515 module. |
| C-MCP-PWR | `J_POWER` | MCP2515 module power | 2 | 5V, GND | Known from schematic and user-confirmed design intent | 5 V module power input. |

## DRV8871 DC motor controller connector inventory

Extracted from `DC_MOTOR_DRIVER_SCH.pdf`.

| Connector ID | Schematic connector | Subsystem | Pin count | Signals | Status | Notes |
|---|---|---|---:|---|---|---|
| C-DRV8871-PWR | `POWER_HEADERS` | DRV8871 motor power | 2 | 12V, GND | Known from schematic; deferred physical verification | Motor-power input; actuator-side supply is interrupted by the panic button by design. |
| C-DRV8871-LOGIC | `J2` | Logic power | 2 | 5V, GND | Known from schematic; deferred physical verification | Logic-power input; logic remains powered during panic-button activation by design. |
| C-DRV8871-CAN | `CAN_HEADER` | CAN connector | 2 | CANH, CANL | Known from schematic; deferred physical verification | SN65HVD230DR CAN bus connector. |
| C-DRV8871-MOTOR | `MOTOR_HEADER` | Motor/encoder header | 6 | M1, M2, 3V3, GND, ENCODER_A, ENCODER_B | Known from schematic, pin order to verify | Motor output plus encoder supply/signals. |

Relevant components: ESP32 NodeMCU, SN65HVD230DR, DRV8871DDA and R1 20k on the ILIM path.

## IBT-2 DC motor controller connector inventory

Extracted from `DC_MOTOR_DRIVER_SCH_IBT2.pdf`.

| Connector ID | Schematic connector | Subsystem | Pin count | Signals | Status | Notes |
|---|---|---|---:|---|---|---|
| C-IBT2-PWR | `POWER_HEADERS` | Board motor power | 2 | 12V, GND | Known from schematic; deferred physical verification | Board-level motor-power header; actuator-side supply is interrupted by the panic button by design. |
| C-IBT2-LOGIC | `J2` | Logic power | 2 | 5V, GND | Known from schematic; deferred physical verification | Logic-power input; logic remains powered during panic-button activation by design. |
| C-IBT2-CAN | `CAN_HEADER` | CAN connector | 2 | CANH, CANL | Known from schematic; deferred physical verification | SN65HVD230DR CAN bus connector. |
| C-IBT2-MOTOR | `MOTOR_HEADER` | Motor/encoder header | 6 | M1, M2, 3V3, GND, ENCODER_A, ENCODER_B | Known from schematic, pin order to verify | Motor and encoder header. |
| C-IBT2-CTRL | `IBT2_CONN` | IBT-2 control interface | 8 | IN1, IN2, 5V, GND and additional IBT-2 interface pins | Known from schematic, exact pin order to verify | 2x4 header to IBT-2. For J2/J3, IBT-2 use is user-confirmed; physical pin order and enable wiring remain deferred. |
| C-IBT2-POWER-OUT | `IBT_POWER_HEADER` | IBT-2 power branch | 2 | 12V, GND | Known from schematic; deferred physical verification | Power branch to IBT-2. |
| C-IBT2-MOTOR-OUT | `IBT_MOTOR_HEADER` | IBT-2 motor branch | 2 | M1, M2 | Known from schematic; deferred physical verification | Motor output branch. |

## Stepper / elevator connector inventory

Extracted from `Stepper Driver v7.pdf` and user-confirmed J5 dual-driver architecture.

| Connector ID | Schematic connector | Subsystem | Pin count | Signals | Status | Notes |
|---|---|---|---:|---|---|---|
| C-STPR-CAN | `J_CAN` | CAN connector | 2 | CANH, CANL | Known from schematic, pin order to verify | CAN bus for stepper/elevator controller. |
| C-STPR-DRV | `J_DRIVERS` | TB6600 driver control | 3 | ENA, DIR, PUL | Known from schematic and firmware | Driver control interface from ESP32. In the current design intent, these signals are distributed in parallel to two TB6600 drivers. |
| C-STPR-5V | `J_5V` | Logic power | 2 | 5V, GND | Known from schematic and design intent | Logic-power input for the J5 controller; remains powered during panic-button activation. |
| C-STPR-TB6600-A-CTRL | TB6600 Motor A control terminals | J5 TB6600 Motor A | 3 | PUL, DIR, ENA | User-confirmed design intent; deferred physical verification | Receives ESP32 `PUL`, `DIR` and `ENA` in parallel with Motor B driver. |
| C-STPR-TB6600-B-CTRL | TB6600 Motor B control terminals | J5 TB6600 Motor B | 3 | PUL, DIR, ENA | User-confirmed design intent; deferred physical verification | Receives ESP32 `PUL`, `DIR` and `ENA` in parallel with Motor A driver. |
| C-STPR-TB6600-A-PWR | TB6600 Motor A power terminals | J5 TB6600 Motor A | 2 | VMOT, GND | Deferred physical verification | Supply voltage pending physical inspection. |
| C-STPR-TB6600-B-PWR | TB6600 Motor B power terminals | J5 TB6600 Motor B | 2 | VMOT, GND | Deferred physical verification | Supply voltage pending physical inspection. |

Visible ESP32 signal mapping from the schematic and firmware:

| Signal | ESP32 GPIO | Status |
|---|---:|---|
| PUL | GPIO5 | Known from schematic and firmware; verify physically. |
| DIR | GPIO18 | Known from schematic and firmware; verify physically. |
| ENA | GPIO19 | Known from schematic and firmware; verify physically. |
| CAN_RX | GPIO21 | Known from schematic and firmware; verify physically. |
| CAN_TX | GPIO22 | Known from schematic and firmware; verify physically. |

## Joint-to-driver assignment to verify

| Joint | Current documented driver | Schematic source | Verification status |
|---|---|---|---|
| J1 | DRV8871 | `DC_MOTOR_DRIVER_SCH.pdf` | To verify physically. |
| J2 | IBT-2 | `DC_MOTOR_DRIVER_SCH_IBT2.pdf` | User-confirmed driver family; physical wiring to verify. |
| J3 | IBT-2 | `DC_MOTOR_DRIVER_SCH_IBT2.pdf` | User-confirmed driver family; physical wiring to verify. |
| J4 | DRV8871 + gripper servo | `DC_MOTOR_DRIVER_SCH.pdf` plus gripper wiring | To verify physically. |
| J5 | Two TB6600 drivers controlling two NEMA 23 motors | `Stepper Driver v7.pdf` plus user-confirmed design intent | Dual-driver parallel `PUL`/`DIR`/`ENA` design confirmed; physical wiring and supply voltage to verify. |

## Physical verification checklist

Use this checklist during the next robot access session.

- [ ] Take a general photo of the electronics layout.
- [ ] Take one close-up photo of the Dell server power supply label.
- [ ] Record the exact Dell power-supply model.
- [ ] Confirm the supply voltage used by both J5 TB6600 drivers.
- [ ] Take one photo of the LM2596S DC-DC converter and its wiring.
- [ ] Confirm 5 V output with a multimeter before connecting logic loads.
- [ ] Take one photo of the panic-button wiring.
- [x] Confirm design intent: panic button cuts actuator power only.
- [ ] Confirm physically that the panic button cuts actuator power only.
- [x] Confirm design intent: Raspberry Pi and ESP32 nodes remain powered after panic-button activation.
- [ ] Confirm physically that Raspberry Pi and ESP32 nodes remain powered after panic-button activation.
- [ ] Photograph CAN bus termination resistors RT1 and RT2.
- [x] Confirm design intent: RT1 and RT2 are 120-ohm terminations at the physical ends of the CAN bus.
- [ ] Confirm physical location of RT1 and RT2.
- [ ] Confirm CANH/CANL connector orientation.
- [x] Confirm MCP2515 module receives 5 V power in the design.
- [ ] Confirm physically that MCP2515 module receives 5 V power.
- [ ] Confirm the specific MCP2515 module used is safe for Raspberry Pi 3.3 V SPI/INT logic.
- [ ] Photograph J1 driver and connector.
- [ ] Photograph J2 IBT-2 driver and connector.
- [ ] Photograph J3 IBT-2 driver and connector.
- [ ] Photograph J4 driver and connector.
- [ ] Photograph both J5 TB6600 drivers and connectors.
- [ ] Record connector type/model if visible.
- [ ] Record pin count and wire color for each connector.
- [ ] Update this file with verified pinouts.

## Information still missing

- Exact connector models or terminal-block types.
- Exact physical pin order for each connector.
- Wire colors.
- Cable gauges for logic, CAN and driver control signals.
- Exact Dell server power-supply model.
- TB6600 supply voltage for the two J5 drivers.
- Physical location of CAN termination resistors RT1 and RT2.
- Exact MCP2515 module model or evidence that it is safe with Raspberry Pi 3.3 V SPI/INT logic while powered from 5 V.
- Final ground-bonding or isolation detail between Power GND and Signal GND.
- Final photos for `electronics/images/`.

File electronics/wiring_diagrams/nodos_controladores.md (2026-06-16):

<!-- SPDX-License-Identifier: CERN-OHL-S-2.0 -->

# Controller nodes

This document summarizes the controller-node architecture for the Assistbelle robotic arm and elevator subsystem.

## Scope

The controller nodes described here correspond to the robotic arm and vertical elevator subsystem. The information is based on the thesis diagrams, firmware pinout documentation, current design notes and user-confirmed build information. Final photos and connector-level pin verification are still required before publication.

## General architecture

The subsystem uses distributed ESP32-based controller nodes connected through CAN using SN65HVD230D CAN transceivers.

| Node | Actuator / subsystem | Current documented driver | Main function | Verification status |
|---|---|---|---|---|
| J1 / Node 1 | Joint 1 / base | DRV8871 | DC motor with quadrature encoder. | Documentation pending: board photo and wiring check. |
| J2 / Node 2 | Joint 2 / shoulder | IBT-2 | DC motor with quadrature encoder. | User-confirmed active; photo and wiring check pending. |
| J3 / Node 3 | Joint 3 / elbow | IBT-2 | DC motor with quadrature encoder. | User-confirmed active; photo and wiring check pending. |
| J4 / Node 4 | Joint 4 / wrist + gripper | DRV8871 + servo | DC motor with encoder and gripper servo control. | Documentation pending: board photo and wiring check. |
| J5 / Node 5 | Vertical elevator / prismatic axis | TB6600 | Stepper motor control for elevator motion. | Documentation pending: board photo and wiring check. |

## Current driver assignment

The current documentation should use the following driver assignment:

| Joint | Driver | Notes |
|---|---|---|
| J1 | DRV8871 | Base joint. |
| J2 | IBT-2 | Shoulder joint; user-confirmed IBT-2 implementation; self-locking mechanical behavior reported when actuator power is cut. |
| J3 | IBT-2 | Elbow joint; user-confirmed IBT-2 implementation; self-locking mechanical behavior reported when actuator power is cut. |
| J4 | DRV8871 + servo | Wrist motor plus gripper servo. |
| J5 | TB6600 | Vertical elevator / prismatic axis. |

## DRV8871-based DC node

The DRV8871-based node is used for J1 and J4 in the current documentation.

Main signals:

| Signal | Function |
|---|---|
| IN1 / PWM control | Motor-drive control input. |
| IN2 / direction control | Motor-drive control input. |
| Encoder A | Quadrature encoder phase A. |
| Encoder B | Quadrature encoder phase B. |
| CAN TX/RX | ESP32 logic communication to CAN transceiver. |
| CANH/CANL | Differential CAN bus lines. |
| 12 V | Motor power rail. |
| 5 V / 3.3 V | Logic rail, depending on module requirements. |
| GND | Ground reference according to the power-distribution strategy. |

## IBT-2-based DC node

The IBT-2-based node is used for J2 and J3. This assignment has been confirmed by the user during the project review, but board photos and exact connector pin mapping are still required for HardwareX publication.

Main signals:

| Signal | Function |
|---|---|
| RPWM | PWM command for one motor direction. |
| LPWM | PWM command for the opposite motor direction. |
| R_EN | Right-side bridge enable. |
| L_EN | Left-side bridge enable. |
| Encoder A | Quadrature encoder phase A. |
| Encoder B | Quadrature encoder phase B. |
| CAN TX/RX | ESP32 logic communication to CAN transceiver. |
| CANH/CANL | Differential CAN bus lines. |
| 12 V | Motor power rail. |
| GND | Ground reference according to the power-distribution strategy. |

Firmware review note: current J2/J3 source definitions expose generic `DRV_IN1` and `DRV_IN2` names. During firmware review, verify whether these map to IBT-2 `RPWM`/`LPWM` with enable pins tied high, or whether firmware must explicitly define `RPWM`, `LPWM`, `R_EN` and `L_EN`.

## TB6600 elevator node

The TB6600-based node is used for the vertical elevator / prismatic axis J5.

Main signals:

| Signal | Function |
|---|---|
| STEP / PUL | Step pulse signal. |
| DIR | Direction signal. |
| EN / ENA | Driver enable signal. |
| CAN TX/RX | ESP32 logic communication to CAN transceiver. |
| CANH/CANL | Differential CAN bus lines. |
| 12 V | Stepper-driver power rail. |
| 5 V | Logic rail. |
| GND | Ground reference according to the power-distribution strategy. |

## Validation checklist for next hardware access

- [ ] Photograph J1 DRV8871 board and wiring.
- [ ] Photograph J2 IBT-2 board and wiring.
- [ ] Photograph J3 IBT-2 board and wiring.
- [ ] Photograph J4 DRV8871 board, wrist motor wiring and gripper servo wiring.
- [ ] Photograph J5 TB6600 board and wiring.
- [ ] Confirm whether J2/J3 IBT-2 enable pins are tied high or controlled by ESP32 GPIO.
- [ ] Confirm power connections: actuator rail, logic rail and grounds.
- [ ] Confirm CAN TX/RX mapping against `electronics/pinout_tables/esp32_pinout_table.md`.
- [ ] Update this document if the physical robot differs from the current documented assignment.

## Related documents

- [`../pinout_tables/esp32_pinout_table.md`](../pinout_tables/esp32_pinout_table.md)
- [`../power_distribution/power_summary.md`](../power_distribution/power_summary.md)
- [`bus_principal.md`](bus_principal.md)
- [`../schematics/schematics_index.md`](../schematics/schematics_index.md)

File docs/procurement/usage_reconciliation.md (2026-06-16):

<!-- SPDX-License-Identifier: CC-BY-4.0 -->

# Procurement usage reconciliation

This document reconciles the purchase evidence, schematic PDFs, firmware/code references, current repository documentation and user-confirmed build information to decide which purchased items are part of the current HardwareX arm/elevator package, which are legacy, and which still need documentation or quantity reconciliation.

## Evidence reviewed

| Evidence source | Use in this reconciliation |
|---|---|
| `docs/bom_template.csv` | Current active BOM baseline. |
| `docs/procurement/purchase_log_public.csv` | Curated public purchase/procurement log. |
| `electronics/schematics/*.pdf` | Electrical design evidence for active electronics blocks. |
| `firmware/esp32_stepper_node/J5_tb6600/` | Code-level evidence for the TB6600 elevator node. |
| `electronics/wiring_diagrams/nodos_controladores.md` | Current documented joint-to-driver assignment. |
| Uploaded expense/liquidation spreadsheets | Source of detailed purchase rows, summarized publicly in `purchase_log_public.csv`. |
| User build confirmation during project review | Confirms that both V-slot/profile families, Dual V wheels, brackets, threaded rod and J2/J3 IBT-2 drivers were used in the build. |

## Usage categories

| Category | Meaning |
|---|---|
| Active | Used by the current HardwareX design or strongly supported by code/schematics/current docs. |
| User-confirmed active / documentation pending | Confirmed as used in the build, but exact placement, quantity, photo or CAD evidence still must be documented for publication. |
| To reconcile | Purchased and probably relevant, but quantity, exact use or BOM mapping must be checked. |
| Legacy / not active | Purchased during development but not part of the current public HardwareX configuration. |
| Tool / consumable | Useful for fabrication/testing but not an installed robot component. |

## Electronics and actuator reconciliation

| Item family | Evidence | Decision | Notes |
|---|---|---|---|
| TB6600 drivers | BOM-038; purchase rows PRC-021/PRC-026; J5 firmware folder and code use TB6600 pins ENA/DIR/PUL. | Active | Final elevator driver family. |
| NEMA23 stepper motors | BOM-034; purchase rows PRC-021/PRC-026; J5 elevator subsystem documentation. | Active | Final elevator actuator family; exact installed motor count/photo still pending. |
| DRV8871 | BOM-014; purchase row PRC-015; DRV8871 schematic; node assignment J1/J4. | Active / physical documentation pending | Current docs assign DRV8871 to J1 and J4; photograph boards and wiring for publication. |
| IBT-2 / BTS7960 | Purchase rows PRC-018/PRC-035/PRC-038; IBT-2 schematic; node assignment J2/J3; user confirmation. | User-confirmed active for J2/J3; excess BTS7960 purchases legacy unless installed | J2 and J3 use IBT-2. Photos are still needed for HardwareX evidence and pinout/wiring verification. |
| DRV8825 / A4988 / NEMA17 | Purchase rows PRC-009 and PRC-032. | Legacy / not active unless a test fixture is documented separately | Current J5 code and docs use TB6600 + NEMA23, not DRV8825/A4988/NEMA17. |
| MCP2515 | Purchase rows PRC-027/PRC-028; Raspberry Pi/MCP2515 schematic and pinout docs. | Active | Current implementation uses 5 V module power with Raspberry Pi 3.3 V SPI/INT compatibility to verify. |
| SN65HVD230 CAN transceivers | BOM-017; schematics for ESP32 nodes. | Active | Used for ESP32 CAN physical layer. |
| LM2596S 5 V converter | BOM-020; purchase row PRC-008; power docs. | Active | Logic 5 V rail. |
| ACS712 current sensors | BOM-005; purchase rows PRC-005/PRC-026. | Active / to place in final wiring | Used for current sensing; exact final placement/photo pending. |

## Mechanical and V-slot reconciliation

The purchase evidence includes two different V-slot/profile families that must be separated and documented as complementary, not mutually exclusive:

1. The current BOM has `Perfil V-Slot 2040` with a total length of 170 cm, described as 60 cm + 60 cm + 50 cm for the elevator frame.
2. The corporate-card liquidation purchase log includes `V-Slot 2020 profiles 70cm x4 and 35cm x2`, totaling 350 cm.

Both profile families were confirmed as used in the build. The remaining task is not to decide whether one replaces the other, but to map each profile family to its exact physical location, orientation and installed length in CAD/photos. The current working note is that the larger profiles and the 2020 profiles serve different structural directions or subassemblies of the elevator/frame, but the final horizontal/vertical allocation must be documented visually.

| Item family | Evidence | Decision | Notes |
|---|---|---|---|
| V-Slot 2040, 170 cm | BOM-036; user confirmation. | User-confirmed active / document placement | Current BOM says 2040 profile, 60+60+50 cm. Map to CAD/photos before final publication. |
| V-Slot 2020, 70 cm x4 + 35 cm x2 | PRC-030; user confirmation. | User-confirmed active / add to installed profile mapping | Purchase evidence says 2020 profile. Confirm exact installed lengths and whether they correspond to vertical, horizontal or secondary frame members. |
| Dual V wheel kit | BOM-035; PRC-013; user confirmation. | User-confirmed active | Used for the elevator ascent/guide system; photo/CAD placement pending. |
| V-2040 wheel/frame kit | BOM-037. | Active as reference/printed model candidate | BOM notes it was delivered and used as a reference for 3D-printed model. |
| KP-08 bearing blocks | PRC-031; T8/KP08 purchase evidence. | Active / fastener table pending | Likely part of lead-screw/elevator support; exact placement pending. |
| KFL08 / T8 screw support | PRC-003/PRC-010; BOM-033. | Active / reconcile duplicate purchases | Both KFL08 and KP08/T8 evidence exist; final quantity to verify. |
| V-slot 90-degree brackets | PRC-023/PRC-031/PRC-033; user confirmation. | User-confirmed active / final count pending | Purchased in multiple rows; final installed quantity pending. |
| Universal double L brackets | PRC-033; user confirmation. | User-confirmed active / final count pending | Needs physical/CAD placement. |
| M5 screws and T-nuts | PRC-031. | Active / final installed count pending | Used with the V-slot system; final installed count pending. |
| Threaded rod 3/16 and hex nuts | PRC-034; user confirmation. | User-confirmed active / document placement | Confirm exact function, installed length and whether all nuts were used or only a subset. |
| Melamine/PVC/screws/adhesives | PRC-019/PRC-025. | Tooling/prototype support unless installed | Do not include as installed BOM unless final robot uses it. |

## Final status by purchase line groups

| Purchase line(s) | Item summary | Status for HardwareX |
|---|---|---|
| PRC-001 to PRC-006 | Worm gear, couplings, T8/KFL08, bearings, ACS712, stainless rod. | Mostly active/to-reconcile against mechanical CAD and BOM. |
| PRC-007 to PRC-008 | ESP32 and LM2596S. | Active. |
| PRC-009 | DRV8825. | Legacy/not active. |
| PRC-010 to PRC-015 | T8/KP08, bearings, wheels, PC817, DRV8871. | Active/to-reconcile; DRV8871 used for J1/J4 per current docs. |
| PRC-016 to PRC-020 | Tape, cable ties, CNY70/BTS7960, consumables, hand saw. | Mixed: consumables/tooling; any BTS7960/IBT-2 corresponding to J2/J3 is active, excess remains legacy. |
| PRC-021 and PRC-026 | TB6600, NEMA23, ACS sensors. | Active, but bundled purchases should be split later. |
| PRC-027 to PRC-028 | MCP2515. | Active. |
| PRC-029 | Micro DC motors. | Active arm actuator evidence. |
| PRC-030 to PRC-034 | V-slot 2020 profiles, KP-08, brackets, fasteners, belt/V-slot kit, threaded rod. | V-slot/brackets/threaded rod user-confirmed active; belt/NEMA17/A4988 portion remains legacy/test unless separately documented. |
| PRC-035 and PRC-038 | BTS7960 purchases. | Active only if they correspond to installed J2/J3 IBT-2 modules; remaining excess legacy. |
| PRC-036 | Metal part fabrication. | Active/to-classify; identify part and drawing. |
| PRC-037 | ESP32/electronic circuit board. | Active/to-reconcile with ESP32 BOM quantity. |
| PRC-039 | Audio interface. | Out of current arm/elevator HardwareX scope unless later justified. |

## Actions before freezing the BOM

- [ ] Photograph J2 and J3 driver boards as IBT-2 evidence for HardwareX and verify their exact ESP32-to-driver pin mapping.
- [ ] Map the physical frame/CAD against both V-Slot 2040 170 cm and V-Slot 2020 70 cm x4 + 35 cm x2.
- [ ] Complete `hardware/fasteners/structural_profiles_table.csv` with installed V-slot/profile/bracket/fastener quantities and physical locations.
- [ ] Document the threaded rod function, installed length and nut usage.
- [ ] Split bundle purchases PRC-021 and PRC-026 into TB6600, NEMA23 and ACS712 lines if final accounting precision is required.
- [ ] Mark DRV8825/A4988/NEMA17 as legacy unless a separate test fixture is documented.
- [ ] Identify the fabricated metal part from PRC-036 and connect it to CAD/drawings/photos.

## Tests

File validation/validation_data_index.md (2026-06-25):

<!-- SPDX-License-Identifier: CC-BY-4.0 -->

# Validation data index

This file summarizes the curated validation evidence currently stored in the repository.

## Uploaded evidence

| Evidence group | Repository path | Status |
|---|---|---|
| Joint-motion CSV/TXT data | `validation/joint_motion_tests/raw/` | Uploaded. |
| Joint-motion plots | `validation/joint_motion_tests/plots/` | Uploaded. |
| Kinematics figures | `validation/kinematics_tests/figures/` | Uploaded. |
| Perception figures | `validation/perception_tests/figures/` | Uploaded. |
| Joint-motion Tracker projects and linked videos | `validation/tracker_files/joint_motion/` | Uploaded through Git LFS. Each tracked `.trk` has its linked `.mp4` in the same folder. |
| Kinematics Tracker projects and linked images | `validation/tracker_files/kinematics/` | Uploaded through Git LFS. Each tracked `.trk` has its linked `.jpeg` in the same folder. |
| Representative validation videos | `validation/media/` | Uploaded through Git LFS for quick reviewer access. |

## Representative videos uploaded

| Evidence group | File | Purpose |
|---|---|---|
| J5 ramp motion | `validation/media/joint_motion/j5_ramp_100.0mm_5reps_robot.mp4` | Elevator response with ramp profile. |
| J5 trapezoidal motion | `validation/media/joint_motion/j5_trap_100.0mm_5reps_robot.mp4` | Elevator response with trapezoidal profile. |
| J1 step motion | `validation/media/joint_motion/j1_step_30.0deg_5reps_robot.mp4` | Representative revolute joint step response. |
| Perception | `validation/media/perception/resultado_percepcion_video_prueba_completa.mp4` | Representative perception test. |
| Teleoperation | `validation/media/teleoperation/Teclado_P2.mp4` | Representative keyboard teleoperation test. |

## Tracker-linked media uploaded

The repository also stores validation media next to the Tracker project files so that reviewers can open each `.trk` directly after cloning with Git LFS enabled.

| Tracker group | Linked media stored next to `.trk` | Purpose |
|---|---:|---|
| Joint motion | 15 `.mp4` files | Full Tracker-linked video evidence for J1-J5 step, ramp and trapezoidal motion tests. |
| Kinematics | 20 `.jpeg` files | Tracker-linked still-image evidence for inverse/direct kinematics measurement cases P1-P5. |

## Local video evidence not yet committed

The historical `resultados/` folder may still contain additional raw videos and intermediate files. These are kept outside the repository unless they are needed for reproducibility or review.

| Local folder | Current decision |
|---|---|
| `validation/media/joint_motion/` | Representative videos uploaded in `validation/media/`; full Tracker-linked set uploaded in `validation/tracker_files/joint_motion/`. |
| `validation/media/kinematics/` | Tracker-linked `.jpeg` evidence uploaded in `validation/tracker_files/kinematics/`. |
| `validation/media/teleoperation/` | Representative `Teclado_P2.mp4` uploaded. Remaining videos can stay local unless needed. |
| `validation/media/perception/` | Main perception video uploaded. |

## Recommended next step

Use `paper/tables/validation_summary.md` as the manuscript-facing summary of the uploaded validation evidence. Keep any remaining raw video material either local or in an external archive if full audiovisual provenance is required.

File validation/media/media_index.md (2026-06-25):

# Índice de media de validación

Este archivo registra videos, capturas o enlaces audiovisuales usados como evidencia de validación.

## Videos representativos versionados

| ID | Archivo | Tipo de prueba | Subsistema | Descripción | Estado |
|---|---|---|---|---|---|
| MED-001 | `validation/media/joint_motion/j5_ramp_100.0mm_5reps_robot.mp4` | Movimiento articular | Elevador J5 | Perfil rampa de 100 mm con 5 repeticiones, vista del robot. | Subido con Git LFS. |
| MED-002 | `validation/media/joint_motion/j5_trap_100.0mm_5reps_robot.mp4` | Movimiento articular | Elevador J5 | Perfil trapezoidal de 100 mm con 5 repeticiones, vista del robot. | Subido con Git LFS. |
| MED-003 | `validation/media/joint_motion/j1_step_30.0deg_5reps_robot.mp4` | Movimiento articular | J1 | Perfil escalón de 30 grados con 5 repeticiones, vista del robot. | Subido con Git LFS. |
| MED-004 | `validation/media/perception/resultado_percepcion_video_prueba_completa.mp4` | Percepción | Visión | Video de prueba completa de percepción. | Subido con Git LFS. |
| MED-005 | `validation/media/teleoperation/Teclado_P2.mp4` | Teleoperación | ROS 2 + CAN | Prueba de movimiento comandado por teclado. | Subido con Git LFS. |

## Videos locales no versionados

Los demás videos de `validation/media/` se mantienen como evidencia local no versionada para evitar subir todo el conjunto audiovisual. Pueden subirse en una versión posterior o enlazarse externamente si se requiere reproducibilidad audiovisual completa.

| Grupo local | Estado |
|---|---|
| `validation/media/joint_motion/` | Solo se versionó un subconjunto representativo. |
| `validation/media/kinematics/` | Pendiente de selección o enlace externo. |
| `validation/media/teleoperation/` | Solo se versionó `Teclado_P2.mp4`. |
| `validation/media/perception/` | Se versionó el video de percepción principal. |

## Criterios de selección

Una evidencia audiovisual se considera útil para publicación si permite verificar al menos uno de estos puntos:

- ejecución de un comando desde ROS 2;
- respuesta de una articulación o del elevador;
- comparación entre perfiles de movimiento;
- funcionamiento del bus CAN;
- funcionamiento integrado del robot;
- manipulación de un objeto o tarea representativa.

## Recomendación de almacenamiento

Si se requiere conservar el conjunto audiovisual completo, se recomienda alojarlo en almacenamiento externo estable y registrar aquí el enlace. Para el repositorio HardwareX se prioriza un subconjunto representativo con Git LFS.

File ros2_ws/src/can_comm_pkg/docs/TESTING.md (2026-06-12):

# Robot Performance Testing Suite

This package includes a set of automated scripts to test the step response, ramp response, and trapezoidal profile tracking for each joint (J1-J5).

## Features

*   **Automated Execution**: Runs a specified number of repetitions for each test.
*   **Data Recording**: Captures Setpoint vs. Measured data for Position, Velocity, and Acceleration.
*   **Advanced Processing**:
    *   **Savitzky-Golay Filtering**: Smooths noisy encoder data.
    *   **Robust Differentiation**: Calculates clean velocity and acceleration derivatives.
*   **Visualization**: Generates plots with error curves.
*   **Data Export**: Automatically saves `.csv` data and `.png` plots to a `resultados` folder.

## Usage

The tests are registered as ROS 2 executables. You can run them using `ros2 run`.

### Command Format

```bash
ros2 run can_comm_pkg j<JOINT>_<PROFILE>
```

*   **JOINT**: `1`, `2`, `3`, `4`, `5`
*   **PROFILE**: `step`, `ramp`, `trap`

### Examples

*   **J1 Step Response**:
    ```bash
    ros2 run can_comm_pkg j1_step
    ```
*   **J4 Trapezoidal Profile**:
    ```bash
    ros2 run can_comm_pkg j4_trap
    ```
*   **J5 Ramp Response**:
    ```bash
    ros2 run can_comm_pkg j5_ramp
    ```

## Parameters

When you run a test, you will be prompted for:

1.  **Target**:
    *   For **J1-J4** (Rotational): Target position in **degrees**.
    *   For **J5** (Linear): Target position in **millimeters**.
2.  **Time**: Duration of the movement in seconds.
3.  **Repetitions**: Number of back-and-forth cycles to perform.

## Output

Results are saved in the `resultados` folder within the directory where you executed the command.

**Files Generated:**
*   `jX_type_TARGET_REPS.csv`: Raw and processed data.
*   `jX_type_TARGET_REPS.png`: Plot of Position, Velocity, and Acceleration with errors.

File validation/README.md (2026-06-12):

# Validación

Esta carpeta contiene las evidencias curadas de validación del robot para la preparación del paquete HardwareX.

La validación debe separar los datos brutos de los datos seleccionados para publicación. Los archivos originales pueden permanecer en `resultados/`, pero las evidencias limpias, renombradas y descritas deben colocarse en `validation/`.

## Objetivo

Documentar que el sistema puede ejecutar pruebas reproducibles de movimiento, comunicación CAN, control desde ROS 2 y operación integrada.

## Subcarpetas

| Carpeta | Contenido esperado |
|---|---|
| `joint_motion_tests/` | Pruebas de articulaciones y elevador: escalón, rampa, trapezoidal y comparaciones. |
| `kinematics_tests/` | Validación de cinemática directa e inversa. |
| `perception_tests/` | Pruebas de visión, lectura de códigos o identificación de objetos. |
| `pick_and_place_tests/` | Pruebas integradas de manipulación. |
| `figures/` | Gráficas finales listas para paper. |
| `media/` | Videos, capturas y enlaces a evidencias audiovisuales. |

## Evidencias actuales identificadas

| Evidencia bruta | Destino recomendado | Tipo de prueba |
|---|---|---|
| `resultados/Teclado_P1.mp4` | `validation/media/teleop_keyboard_test.mp4` | Teleoperación por teclado. |
| `resultados/j5_ramp_100.0mm_5reps.mp4` | `validation/media/j5_ramp_100mm_5reps.mp4` | Elevador J5 con perfil rampa. |
| `resultados/j5_trap_100.0mm_5reps.mp4` | `validation/media/j5_trapezoidal_100mm_5reps.mp4` | Elevador J5 con perfil trapezoidal. |

## Criterio para aceptar una evidencia

Cada evidencia debe tener:

- nombre de archivo claro;
- tipo de prueba;
- fecha o versión del sistema, si está disponible;
- descripción breve;
- parámetros principales de la prueba;
- resultado observado;
- relación con firmware, ROS 2 o hardware probado.

## Comandos sugeridos para mover evidencias locales

```bash
cd ~/robot-project

mkdir -p validation/media

cp "resultados/Teclado_P1.mp4" "validation/media/teleop_keyboard_test.mp4"
cp "resultados/j5_ramp_100.0mm_5reps.mp4" "validation/media/j5_ramp_100mm_5reps.mp4"
cp "resultados/j5_trap_100.0mm_5reps.mp4" "validation/media/j5_trapezoidal_100mm_5reps.mp4"
```

Si los videos son muy pesados, se recomienda no versionarlos directamente en GitHub. En ese caso, subirlos a almacenamiento externo y registrar los enlaces en `validation/media/media_index.md`.

## Orden recomendado de trabajo

1. Registrar videos en `validation/media/media_index.md`.
2. Mover o enlazar evidencias seleccionadas.
3. Crear tablas resumen en `joint_motion_tests/` y `pick_and_place_tests/`.
4. Generar figuras finales en `validation/figures/`.
5. Referenciar los resultados desde el manuscrito en `paper/`.

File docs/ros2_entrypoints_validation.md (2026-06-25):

# Validación de entry points ROS 2

Este documento lista los comandos principales del paquete `can_comm_pkg` y define una rutina de validación reproducible.

## Fuente

Los entry points se definen en:

```text
ros2_ws/src/can_comm_pkg/setup.py
```

El archivo `setup.py` es la referencia principal para los comandos instalables del paquete.

## Preparación del entorno

```bash
cd ~/robot-project/ros2_ws
source /opt/ros/jazzy/setup.bash
colcon build --packages-select can_comm_pkg
source install/setup.bash
```

## CAN virtual para pruebas sin hardware

```bash
sudo modprobe vcan
sudo ip link add dev can0 type vcan 2>/dev/null || true
sudo ip link set up can0
ip link show can0
```

## Comandos principales

| Comando | Función | Estado |
|---|---|---|
| `can_node` | Nodo base SocketCAN, publica/recibe mensajes CAN. | Validado con `vcan`. |
| `can_cli` | Interfaz CLI para comandos CAN. | Pendiente de prueba local. |
| `can_slider` | Interfaz con sliders para control articular. | Pendiente de prueba local. |
| `can_traj` | Ejecución de trayectorias. | Pendiente de prueba local. |
| `can_traj_offline` | Generación/validación offline de trayectorias. | Pendiente de prueba local. |
| `ik_node` | Nodo de cinemática inversa. | Pendiente de prueba local. |
| `control_teclado` | Control por teclado. | Evidencia de video identificada. |
| `control_teclado_trapezoidal` | Control por teclado con perfil trapezoidal. | Pendiente de prueba local. |
| `barcode_detector` | Detección de códigos de barras. | Pendiente de prueba local. |
| `product_identifier` | Identificación de producto. | Pendiente de clasificar como nodo ROS o helper standalone. |

## Rutina mínima de prueba

En una terminal:

```bash
cd ~/robot-project/ros2_ws
source install/setup.bash
ros2 run can_comm_pkg can_node
```

En otra terminal:

```bash
cd ~/robot-project/ros2_ws
source install/setup.bash
ros2 run can_comm_pkg control_teclado
```

## Pruebas de trayectoria J5

```bash
ros2 run can_comm_pkg j5_step
ros2 run can_comm_pkg j5_ramp
ros2 run can_comm_pkg j5_trap
```

Estas pruebas deben relacionarse con:

```text
validation/media/j5_ramp_100mm_5reps.mp4
validation/media/j5_trapezoidal_100mm_5reps.mp4
validation/joint_motion_tests/j5_motion_summary.csv
```

## Compatibilidad CAN J5

La implementación ROS 2 actual usa el topic `can_command` y `can_node.py` para convertir strings como `C5:100.0` a una trama CAN `0xC5`.

| Mensaje | ROS 2 actual | Firmware J5 actual | Compatibilidad |
|---|---|---|---|
| `C5` | Envía `float32` little-endian en mm. | Acepta `float32` little-endian en mm y también `int16` big-endian en mm. | Compatible para comando de posición. |
| `A5` / `A6` | Solicitud sin payload. | Responde `B5`. | Compatible para solicitud. |
| `B5` | Espera `float32 position` + `float32 velocity`. | Envía `float32 position_mm` + bytes reservados/status `04 00 00 80`. | Parcial: posición compatible, velocidad no cerrada. |

Antes de la validación física final se debe cerrar una decisión:

- actualizar firmware J5 para que `B5` envíe `position_mm` + `velocity_mm_s` como dos `float32` little-endian; o
- modificar ROS 2 para tratar `B5` como caso especial con bytes 4..7 reservados.

La opción recomendada es actualizar firmware J5 para responder `B5` con dos `float32`, usando `0.0f` como velocidad si no se mide velocidad lineal.

## Cierre de CAN virtual

```bash
sudo ip link delete can0
```

## Resultado esperado

El objetivo mínimo sin hardware físico es confirmar que:

- el paquete compila;
- `can_node` inicia con `can0` virtual;
- los entry points existen;
- los comandos no fallan por importaciones faltantes;
- `C5` se genera en mm como `float32` little-endian;
- los módulos principales quedan listos para prueba física posterior.

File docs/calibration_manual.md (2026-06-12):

# Manual de calibración

## Pasos mínimos

1. Definir cero mecánico de J1 a J5.
2. Verificar dirección de lectura de encoders.
3. Verificar respuesta de cada nodo CAN.
4. Verificar cámara y foco.
5. Ejecutar pruebas de rampa.
6. Ejecutar pruebas trapezoidales.
7. Guardar notas de calibración junto con los datos de validación.

## Pendiente

Agregar valores reales de calibración, offsets, límites y fotos del procedimiento.

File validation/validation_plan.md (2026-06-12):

# Plan de validación

Este documento define las pruebas mínimas necesarias para respaldar el paquete de publicación HardwareX.

## Objetivo general

Validar que el robot puede ejecutar movimientos reproducibles mediante ROS 2, bus CAN y firmware ESP32, y que existe evidencia suficiente para documentar funcionamiento, limitaciones y repetibilidad.

## Matriz de pruebas

| ID | Prueba | Subsistema | Evidencia esperada | Estado |
|---|---|---|---|---|
| VAL-001 | Compilación ESP-IDF J1-J5 | Firmware | Registro de compilación local | Completado localmente |
| VAL-002 | Compilación ROS 2 `can_comm_pkg` | Software | `colcon build` exitoso | Completado localmente |
| VAL-003 | Inicio de `can_node` con `vcan` | ROS 2 / CAN | Log de nodo iniciado | Completado localmente |
| VAL-004 | Teleoperación por teclado | ROS 2 / CAN | Video y notas de prueba | Evidencia bruta identificada |
| VAL-005 | J5 rampa 100 mm, 5 repeticiones | Elevador | Video y tabla resumen | Evidencia bruta identificada |
| VAL-006 | J5 trapezoidal 100 mm, 5 repeticiones | Elevador | Video y tabla resumen | Evidencia bruta identificada |
| VAL-007 | Bus CAN físico | Electrónica | `candump` y respuesta de nodos | Pendiente con hardware |
| VAL-008 | Pick-and-place integrado | Sistema completo | Video, tiempo de ciclo y éxito/falla | Pendiente |
| VAL-009 | Percepción / lectura | Visión | Logs, aciertos y tiempos | Pendiente |
| VAL-010 | Cinemática | Modelo del robot | Tabla de objetivo vs medición | Pendiente |

## Criterios mínimos por prueba

Cada prueba debe incluir:

- identificador de prueba;
- objetivo;
- subsistema evaluado;
- configuración usada;
- comando o procedimiento;
- evidencia obtenida;
- resultado observado;
- limitaciones o incidencias.

## Criterios de publicación

Para el artículo no es necesario presentar todas las pruebas como si fueran ensayos certificados. Sí es necesario que cada evidencia sea trazable y que el lector pueda entender qué se probó, cómo se probó y qué resultado se obtuvo.

## Prioridad inmediata

1. Registrar videos existentes en `validation/media/media_index.md`.
2. Crear tablas resumen para J5 rampa y trapezoidal.
3. Probar entry points ROS 2 adicionales.
4. Preparar figuras comparativas para `validation/figures/`.
5. Documentar pruebas físicas CAN cuando los ESP32 estén disponibles.

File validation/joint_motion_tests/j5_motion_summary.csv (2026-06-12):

test_id | profile | axis | target_displacement_mm | repetitions | evidence_file | command_source | observed_result | status | notes
VAL-005 | ramp | J5 | 100 | 5 | validation/media/j5_ramp_100mm_5reps.mp4 | ROS2_CAN | Elevator motion evidence identified | pending_media_copy | Video source exists in resultados and should be copied or externally linked
VAL-006 | trapezoidal | J5 | 100 | 5 | validation/media/j5_trapezoidal_100mm_5reps.mp4 | ROS2_CAN | Elevator motion evidence identified | pending_media_copy | Recommended operational profile for smoother motion comparison

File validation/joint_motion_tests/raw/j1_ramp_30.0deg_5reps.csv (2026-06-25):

t | q_sp | dq_sp | ddq_sp | q_meas | dq_meas | ddq_meas | q_err | dq_err | ddq_err
4.291534423828125000e-05 | 2.384185791015625000e-06 | 1.000000000000000000e+01 | 0.000000000000000000e+00 | -4.218264241012073534e-02 | 1.584219781089347245e+00 | 2.985603521675368555e+01 | 4.218502659591175097e-02 | 8.415780218910651200e+00 | -2.985603521675368555e+01
1.026201248168945312e-02 | 1.021933555603027344e-01 | 1.000000000000000000e+01 | 0.000000000000000000e+00 | -3.612619249229483132e-02 | 2.034154126261629614e+00 | 3.160063755583152911e+01 | 1.383195480525975518e-01 | 7.965845873738370386e+00 | -3.160063755583152911e+01
2.042293548583984375e-02 | 2.038025856018066406e-01 | 1.000000000000000000e+01 | 0.000000000000000000e+00 | -7.426711427642360142e-02 | 2.526297294270805516e+00 | 3.303768377655715227e+01 | 2.780696998782302698e-01 | 7.473702705729195372e+00 | -3.303768377655715227e+01
3.066778182983398438e-02 | 3.062510490417480469e-01 | 1.000000000000000000e+01 | 0.000000000000000000e+00 | -8.958396559208042786e-02 | 3.056270226605424245e+00 | 3.411313981740894263e+01 | 3.958350146338284747e-01 | 6.943729773394575311e+00 | -3.411313981740894263e+01
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

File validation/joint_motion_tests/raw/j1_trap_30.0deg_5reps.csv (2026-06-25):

t | q_sp | dq_sp | ddq_sp | q_meas | dq_meas | ddq_meas | q_err | dq_err | ddq_err
4.696846008300781250e-05 | 0.000000000000000000e+00 | 0.000000000000000000e+00 | 1.499999999999999822e+01 | -1.171240562343267046e-02 | -6.778224922668477093e-02 | 2.895847419676824686e+00 | 1.171240562343267046e-02 | 6.778224922668477093e-02 | 1.210415258032317354e+01
1.036739349365234375e-02 | 7.988337965514347161e-04 | 1.548063755035400391e-01 | 1.499999999999999822e+01 | -1.171240562343267046e-02 | -8.249271591611602450e-02 | 3.877989254613748660e+00 | 1.251123941998410517e-02 | 2.372990914196560219e-01 | 1.112201074538625001e+01
2.057313919067382812e-02 | 3.159927636460224676e-03 | 3.078925609588622492e-01 | 1.499999999999999822e+01 | -1.154893869219146031e-02 | -1.095573241344839216e-01 | 5.000024096179058297e+00 | 1.470886632865168499e-02 | 4.174498850933461847e-01 | 9.999975903820940815e+00
3.073740005493164062e-02 | 7.064269436085623965e-03 | 4.603564739227294922e-01 | 1.499999999999999822e+01 | -1.288119418180731779e-02 | -1.355009205010414830e-01 | 6.256317378825876574e+00 | 1.994546361789294175e-02 | 5.958573944237710585e-01 | 8.743682621174121650e+00
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

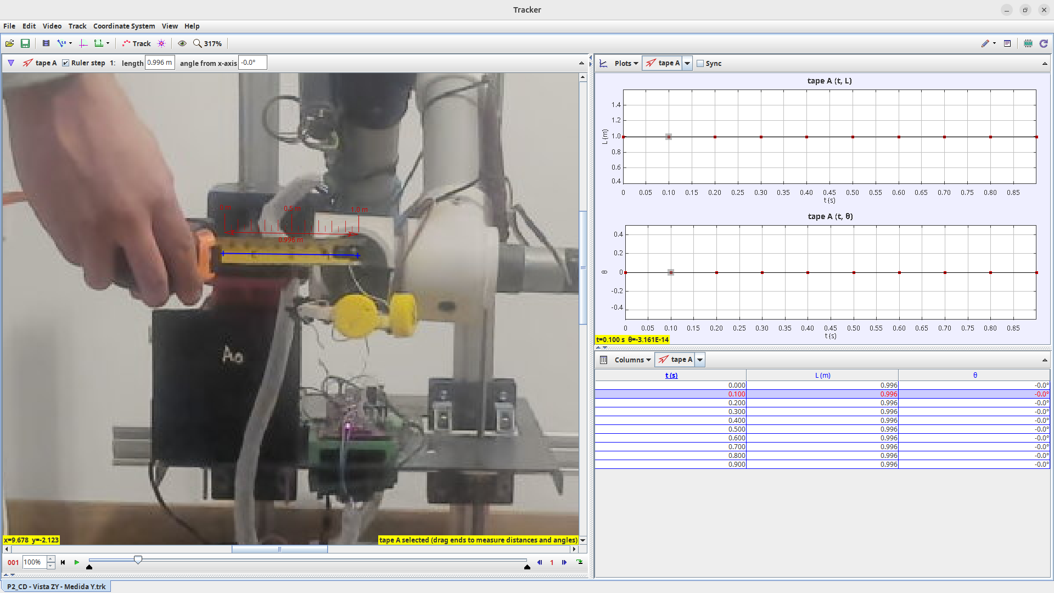
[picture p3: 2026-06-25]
validation/kinematics_tests/figures/CD_P2_VistaZY_MedicionY.png

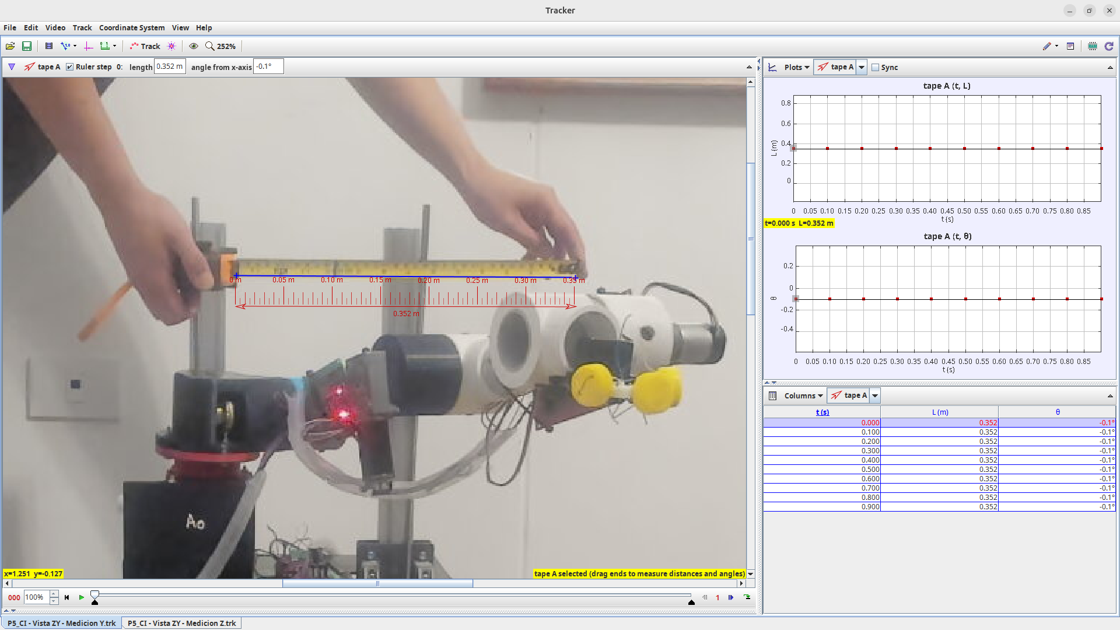
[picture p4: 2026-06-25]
validation/kinematics_tests/figures/P5_CI - Vista ZY- Vista Y.png

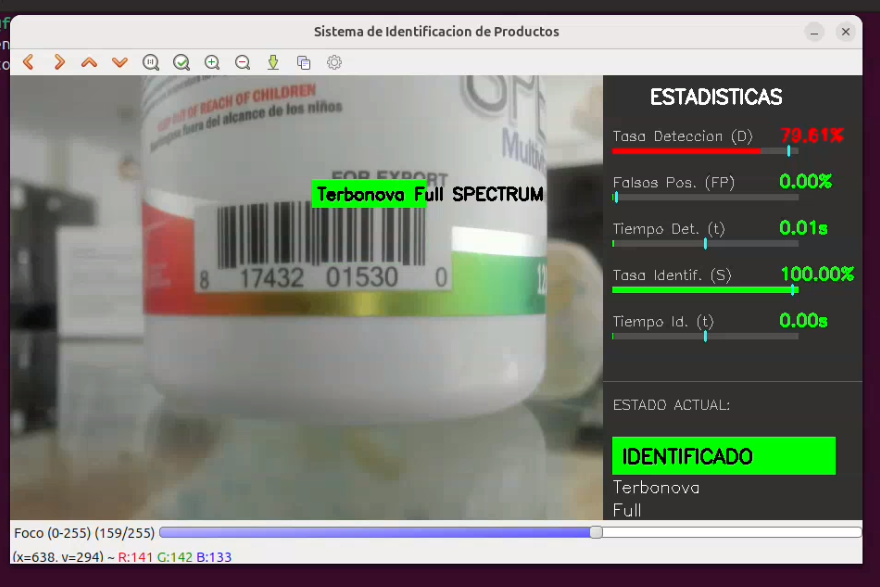
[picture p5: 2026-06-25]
validation/perception_tests/figures/resultado_percepcion2.png

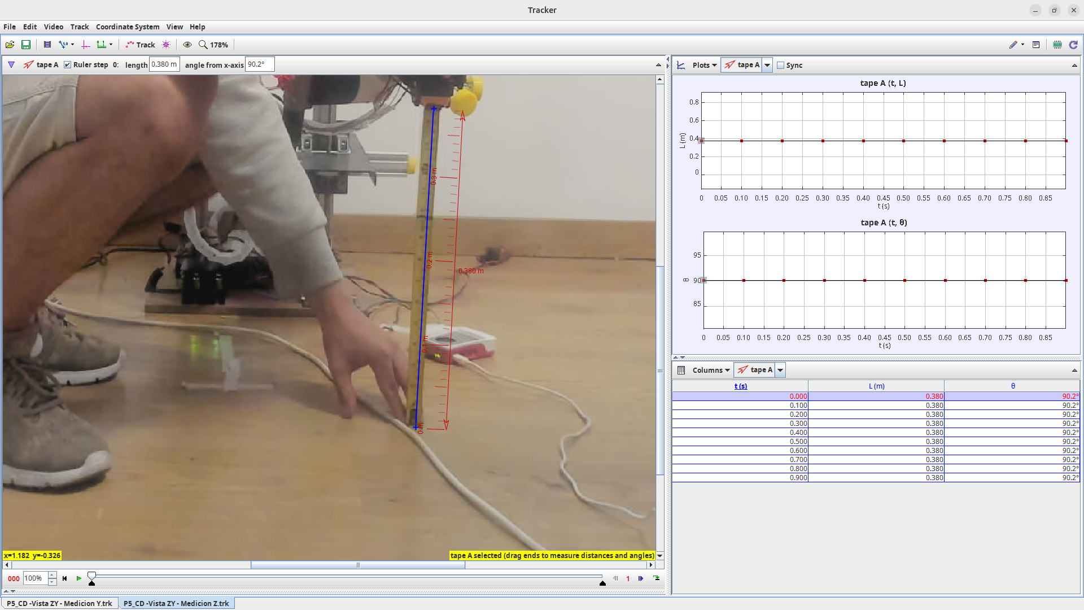
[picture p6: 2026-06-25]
validation/kinematics_tests/figures/CD_P5_VistaZY_MedicionZ.png

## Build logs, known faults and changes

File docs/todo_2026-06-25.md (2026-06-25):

<!-- SPDX-License-Identifier: CC-BY-4.0 -->

# Tasks for 2026-06-25

## Priority 1 - Validation package closure

- [ ] Run a clean local check of Tracker projects from `validation/tracker_files/joint_motion/` and `validation/tracker_files/kinematics/`.
- [ ] Verify that at least one `.trk` per joint J1-J5 opens with its linked `.mp4` without asking for a file path.
- [ ] Verify that at least one kinematics `.trk` for P1-P5 opens with its linked `.jpeg` without asking for a file path.
- [ ] Review `paper/tables/validation_summary.md` and adjust wording for the final manuscript.
- [ ] Decide whether the representative videos in `validation/media/` are still needed now that full Tracker-linked media exist under `validation/tracker_files/`.
- [ ] Add a short reviewer note explaining that cloning requires Git LFS: `git lfs install` and `git lfs pull`.

## Priority 2 - HardwareX manuscript tables and figures

- [ ] Convert `paper/tables/validation_summary.md` into a manuscript-ready table.
- [ ] Select final validation figures from `validation/joint_motion_tests/plots/` for the paper.
- [ ] Prepare a compact validation-results paragraph for J5 ramp, J5 trap, J1 step, perception and teleoperation.
- [ ] Prepare figure captions for validation videos/Tracker evidence if used as supplementary files.

## Priority 3 - Repository cleanup

- [ ] Run `git status --short` and confirm the working tree is clean.
- [ ] Run `git lfs ls-files` and confirm CAD, Tracker files and videos are under LFS.
- [ ] Run a quick README link/path check for validation-related files.
- [ ] Update `docs/publication_checklist.md` manually if needed, marking Tracker-linked media as uploaded and tested.
- [ ] Confirm `validation/media/media_index.md` and `validation/validation_data_index.md` match the final validation structure.

## Priority 4 - Mechanical/electronics pending items

- [ ] Continue the CAD/BOM review for remaining mechanical parts if v60 is still the working snapshot.
- [ ] Confirm pending physical details when the robot is accessible: TB6600 supply voltage, connector pin order, wire colors and electronics photos.
- [ ] Do not change firmware J5/B5 behavior until the physical robot is available for validation.

## Suggested start command

```bash
cd ~/assistbelle-arm-elevator-subsystem
git pull
git status --short
git lfs ls-files | grep -E "validation/tracker_files|validation/media|hardware/(cad|step|stl|drawings)"
```

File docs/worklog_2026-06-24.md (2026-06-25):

<!-- SPDX-License-Identifier: CC-BY-4.0 -->

# Worklog - 2026-06-24

## Validation and Tracker reproducibility updates

Today the repository validation evidence was reorganized and expanded for HardwareX-style review.

## Completed

- Added representative validation videos to `validation/media/` through Git LFS.
- Confirmed the representative videos are real LFS files after pulling locally.
- Added full Tracker-linked joint-motion videos next to their `.trk` files in `validation/tracker_files/joint_motion/`.
- Added Tracker-linked kinematics `.jpeg` images next to their `.trk` files in `validation/tracker_files/kinematics/`.
- Normalized one kinematics Tracker path that pointed to an old local `Pictures/Camera` location.
- Confirmed the tested joint-motion `.trk` opens directly with its linked `.mp4` without manual file search.
- Confirmed the tested kinematics `.trk` opens directly with its linked `.jpeg` without manual file search.
- Updated `.gitattributes` to keep Markdown indexes inside `validation/media/` as normal text, while keeping media in Git LFS.
- Updated `validation/validation_data_index.md` to explain the uploaded Tracker-linked media.
- Added `paper/tables/validation_summary.md` as a manuscript-facing validation evidence table.

## Key commits

| Commit | Summary |
|---|---|
| `e93ec27` | Add representative validation videos. |
| `c817156` | Update media index after representative video upload. |
| `e8cd64b` | Update validation data index after video upload. |
| `c74422c` | Exclude validation media Markdown from LFS. |
| `b0d571d` | Add Tracker-linked validation media. |
| `972870c` | Update validation data index for Tracker-linked media. |
| `06ad5b1` | Add validation summary table. |

## Current status

- Repository is synchronized on `main`.
- Working tree was clean after pulling the documentation updates.
- Tracker reproducibility is confirmed for at least one joint-motion project and one kinematics project.
- Remaining local raw media can stay excluded locally unless needed later.

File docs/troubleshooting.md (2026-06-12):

# Troubleshooting

Esta guia registra errores reales encontrados durante la preparacion de la rama HardwareX.

## 1. Error al abrir una terminal nueva: `setup.bash: No such file or directory`

### Sintoma

Al abrir una nueva terminal aparece algo como:

```text
bash: /home/f15/rosario_ws/install/setup.bash: No such file or directory
```

### Causa

El archivo `.bashrc` esta intentando cargar automaticamente un workspace ROS que ya no existe o que todavia no fue compilado.

### Solucion rapida

Abrir `.bashrc`:

```bash
nano ~/.bashrc
```

Buscar lineas parecidas a:

```bash
source /home/f15/rosario_ws/install/setup.bash
source /home/f15/robot-project/ros2_ws/install/setup.bash
```

Comentar la linea antigua o inexistente:

```bash
# source /home/f15/rosario_ws/install/setup.bash
```

Para el workspace actual, usar carga condicional:

```bash
if [ -f "$HOME/robot-project/ros2_ws/install/setup.bash" ]; then
  source "$HOME/robot-project/ros2_ws/install/setup.bash"
fi
```

Guardar y recargar:

```bash
source ~/.bashrc
```

## 2. Error ROS 2: `OSError: [Errno 19] No such device`

### Sintoma

Al ejecutar:

```bash
ros2 run can_comm_pkg can_node
```

aparece:

```text
OSError: [Errno 19] No such device
```

### Causa

El nodo intenta abrir la interfaz CAN `can0`, pero el sistema operativo no tiene una interfaz `can0` activa. Esto es normal si no esta conectada la interfaz CAN fisica o si todavia no se configuro SocketCAN.

### Verificacion

```bash
ip link show
```

Si no aparece `can0`, el nodo no puede iniciar contra hardware real.

### Opcion A: usar CAN fisico

Con MCP2515 o interfaz CAN conectada:

```bash
sudo ip link set can0 down 2>/dev/null || true
sudo ip link set can0 up type can bitrate 500000
ip -details link show can0
candump can0
```

### Opcion B: probar sin hardware usando CAN virtual

```bash
sudo modprobe vcan
sudo ip link add dev can0 type vcan
sudo ip link set up can0
ip link show can0
```

Luego:

```bash
ros2 run can_comm_pkg can_node
```

Para eliminar la interfaz virtual:

```bash
sudo ip link delete can0
```

## 3. Advertencias ROS 2 sobre `ROS_LOCALHOST_ONLY`

### Sintoma

Aparecen advertencias como:

```text
ROS_LOCALHOST_ONLY is deprecated
```

### Causa

Es una advertencia de configuracion de ROS 2. No impide compilar ni ejecutar el paquete.

### Solucion opcional

Revisar `.bashrc` y quitar configuraciones antiguas de `ROS_LOCALHOST_ONLY` si no se usan.

## 4. Error ESP-IDF: `idf.py: command not found`

### Causa

ESP-IDF no esta cargado en la terminal.

### Solucion

Cargar ESP-IDF desde la instalacion externa:

```bash
source /media/F15/Data/ESP_IDF_CONTAINER/v5.3.3/esp-idf/export.sh
idf.py --version
```

## 5. Error ESP-IDF: `No module named click`

### Causa

El entorno Python de ESP-IDF esta incompleto.

### Solucion

```bash
export IDF_PATH=/media/F15/Data/ESP_IDF_CONTAINER/v5.3.3/esp-idf
/usr/bin/python3 "$IDF_PATH/tools/idf_tools.py" install-python-env
source "$IDF_PATH/export.sh"
idf.py --version
```

## 6. Checks generales

- Verificar que la interfaz CAN este activa.
- Verificar que cada nodo ESP32 tenga energia.
- Verificar que CANH y CANL no esten invertidos.
- Verificar resistencias de terminacion de 120 ohmios en los extremos del bus.
- Verificar que el entorno ROS 2 este cargado.
- Verificar dependencias Python.
- Verificar indice de camara antes de correr scripts de vision.

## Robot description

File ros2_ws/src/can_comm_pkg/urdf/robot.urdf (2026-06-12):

<?xml version="1.0"?>
<robot name="custom_robot">

  <!-- Materials -->
  <material name="blue">
    <color rgba="0 0 0.8 1"/>
  </material>
  <material name="green">
    <color rgba="0 0.8 0 1"/>
  </material>
  <material name="red">
    <color rgba="0.8 0 0 1"/>
  </material>
  <material name="white">
    <color rgba="1 1 1 1"/>
  </material>
  <material name="grey">
    <color rgba="0.5 0.5 0.5 1"/>
  </material>

  <!-- Base Link -->
  <link name="base_link">
    <visual>
      <geometry>
        <box size="0.2 0.2 0.05"/>
      </geometry>
      <material name="grey"/>
    </visual>
  </link>

  <!-- J5: Prismatic (Elevator) -->
  <!-- d0_eff = d0 + 0.80. We place the joint at 0.80 offset? 
       Actually, usually the joint origin is the zero position.
       If d0=0, we want the link to be at 0.80.
       So let's put the joint origin at 0 0 0.80 relative to base?
       Or put it at 0 and have the link offset?
       Let's put joint at 0,0,0 and use d0 as the variable.
       But the DH says d0_eff = d0 + 0.80.
       So the transform is Trans_z(d0 + 0.80).
       This is Trans_z(0.80) * Trans_z(d0).
       So we can have a fixed joint for the 0.80 offset, then the prismatic.
  -->
  
  <joint name="joint_base_offset" type="fixed">
    <parent link="base_link"/>
    <child link="elevator_base"/>
    <origin xyz="0 0 0.80" rpy="0 0 0"/>
  </joint>

  <link name="elevator_base">
     <visual>
      <geometry>
        <cylinder length="1.6" radius="0.02"/>
      </geometry>
      <origin xyz="0 0 -0.8" rpy="0 0 0"/> <!-- Visual representation of the rail -->
      <material name="grey"/>
    </visual>
  </link>

  <joint name="J5" type="prismatic">
    <parent link="elevator_base"/>
    <child link="link_elevator"/>
    <origin xyz="0 0 0" rpy="0 0 0"/>
    <axis xyz="0 0 1"/>
    <limit lower="-0.5" upper="0.5" effort="100" velocity="1.0"/> <!-- Adjust limits as needed -->
  </joint>

  <link name="link_elevator">
    <visual>
      <geometry>
        <box size="0.1 0.1 0.1"/>
      </geometry>
      <material name="blue"/>
    </visual>
  </link>

  <!-- J1: Revolute -->
  <!-- DH: d=0.065, a=0.025, alpha=-90. Theta = th1 + pi -->
  <!-- Origin relative to previous frame (elevator) is just 0 0 0 because we are at the end of the prismatic. -->
  <!-- But we have the +pi offset. -->
  
  <joint name="J1" type="revolute">
    <parent link="link_elevator"/>
    <child link="link_1_pre"/>
    <origin xyz="0 0 0" rpy="0 0 3.14159"/> <!-- Offset pi -->
    <axis xyz="0 0 1"/>
    <limit lower="-3.14" upper="3.14" effort="100" velocity="1.0"/>
  </joint>

  <link name="link_1_pre">
      <!-- Dummy link for the transform -->
  </link>

  <!-- Transform to next joint (Fixed) -->
  <!-- DH Row 1 Params: d=0.065, a=0.025, alpha=-90 -->
  <!-- This defines the position of the NEXT frame relative to J1 -->
  
  <joint name="joint_1_trans" type="fixed">
    <parent link="link_1_pre"/>
    <child link="link_1"/>
    <origin xyz="0.025 0 0.065" rpy="-1.5708 0 0"/>
  </joint>

  <link name="link_1">
    <visual>
      <geometry>
        <cylinder length="0.1" radius="0.03"/>
      </geometry>
      <material name="green"/>
    </visual>
  </link>

  <!-- Fixed Joint (Dummy Row 2) -->
  <!-- DH Row 2 Params: d=0.10, a=0.0, alpha=0. Theta=0 -->
  
  <joint name="joint_dummy" type="fixed">
    <parent link="link_1"/>
    <child link="link_dummy"/>
    <origin xyz="0 0 0.10" rpy="0 0 0"/>
  </joint>

  <link name="link_dummy">
      <!-- Just a connector -->
  </link>

  <!-- J2: Revolute -->
  <!-- DH Row 3 Params: d=0.0, a=0.215, alpha=0. Theta = th2 + pi -->
  
  <joint name="J2" type="revolute">
    <parent link="link_dummy"/>
    <child link="link_2_pre"/>
    <origin xyz="0 0 0" rpy="0 0 3.14159"/> <!-- Offset pi -->
    <axis xyz="0 0 1"/>
    <limit lower="-3.14" upper="3.14" effort="100" velocity="1.0"/>
  </joint>

  <link name="link_2_pre">
  </link>

  <!-- Transform to next joint -->
  <!-- DH Row 3 Params: d=0.0, a=0.215, alpha=0 -->
  
  <joint name="joint_2_trans" type="fixed">
    <parent link="link_2_pre"/>
    <child link="link_2"/>
    <origin xyz="0.215 0 0" rpy="0 0 0"/>
  </joint>

  <link name="link_2">
    <visual>
      <geometry>
        <box size="0.215 0.05 0.05"/>
      </geometry>
      <origin xyz="-0.1075 0 0" rpy="0 0 0"/> <!-- Center the visual -->
      <material name="red"/>
    </visual>
  </link>

  <!-- J3: Revolute -->
  <!-- DH Row 4 Params: d=0.0, a=0.250, alpha=180. Theta = th3 -->
  
  <joint name="J3" type="revolute">
    <parent link="link_2"/>
    <child link="link_3_pre"/>
    <origin xyz="0 0 0" rpy="0 0 0"/>
    <axis xyz="0 0 1"/>
    <limit lower="-3.14" upper="3.14" effort="100" velocity="1.0"/>
  </joint>

  <link name="link_3_pre">
  </link>

  <!-- Transform to next joint -->
  <!-- DH Row 4 Params: d=0.0, a=0.250, alpha=180 -->
  
  <joint name="joint_3_trans" type="fixed">
    <parent link="link_3_pre"/>
    <child link="link_3"/>
    <origin xyz="0.250 0 0" rpy="3.14159 0 0"/>
  </joint>

  <link name="link_3">
    <visual>
      <geometry>
        <box size="0.250 0.04 0.04"/>
      </geometry>
      <origin xyz="-0.125 0 0" rpy="0 0 0"/>
      <material name="white"/>
    </visual>
  </link>

  <!-- J4: Revolute -->
  <!-- DH Row 5 Params: d=0.0, a=0.125, alpha=0. Theta = -th4 -->
  <!-- Note: Axis is 0 0 -1 because of -th4 -->
  
  <joint name="J4" type="revolute">
    <parent link="link_3"/>
    <child link="link_4_pre"/>
    <origin xyz="0 0 0" rpy="0 0 0"/>
    <axis xyz="0 0 -1"/>
    <limit lower="-3.14" upper="3.14" effort="100" velocity="1.0"/>
  </joint>

  <link name="link_4_pre">
  </link>

  <!-- Transform to End Effector -->
  <!-- DH Row 5 Params: d=0.0, a=0.125, alpha=0 -->
  
  <joint name="joint_ee_trans" type="fixed">
    <parent link="link_4_pre"/>
    <child link="link_ee"/>
    <origin xyz="0.125 0 0" rpy="0 0 0"/>
  </joint>

  <link name="link_ee">
    <visual>
      <geometry>
        <sphere radius="0.03"/>
      </geometry>
      <material name="blue"/>
    </visual>
  </link>

</robot>

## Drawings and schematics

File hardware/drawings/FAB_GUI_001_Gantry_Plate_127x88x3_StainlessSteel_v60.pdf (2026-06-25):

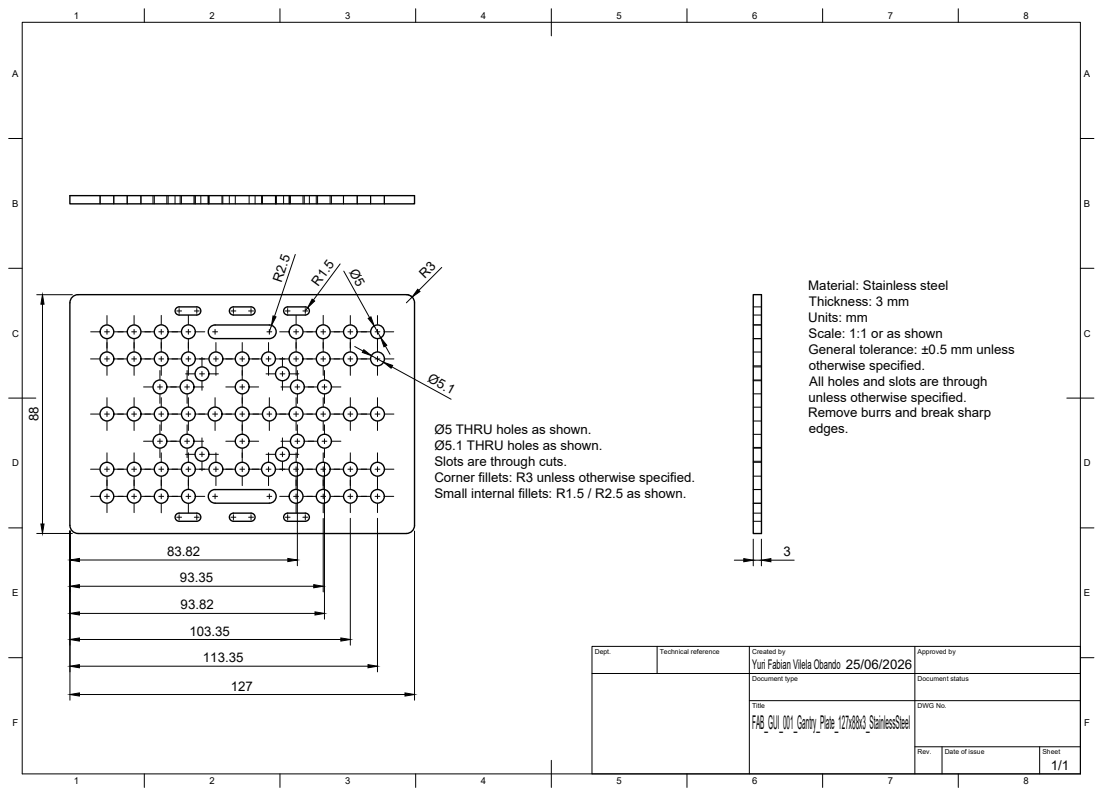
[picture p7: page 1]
Title; DWG No.; Rev.; Date of issue; Sheet; Ø5 THRU holes as shown.; edges.

Material: Stainless steel
Thickness: 3 mm
Units: mm
Scale: 1:1 or as shown
General tolerance: ±0.5 mm unless
otherwise specified.
All holes and slots are through
unless otherwise specified.
Remove burrs and break sharp

Ø5.1 THRU holes as shown.
Slots are through cuts.
Corner fillets: R3 unless otherwise specified.
Small internal fillets: R1.5 / R2.5 as shown.

Dept. | Technical reference | Created by Yuri Fabian Vilela Obando 25/06/2026 | Approved by

Document type | Document status

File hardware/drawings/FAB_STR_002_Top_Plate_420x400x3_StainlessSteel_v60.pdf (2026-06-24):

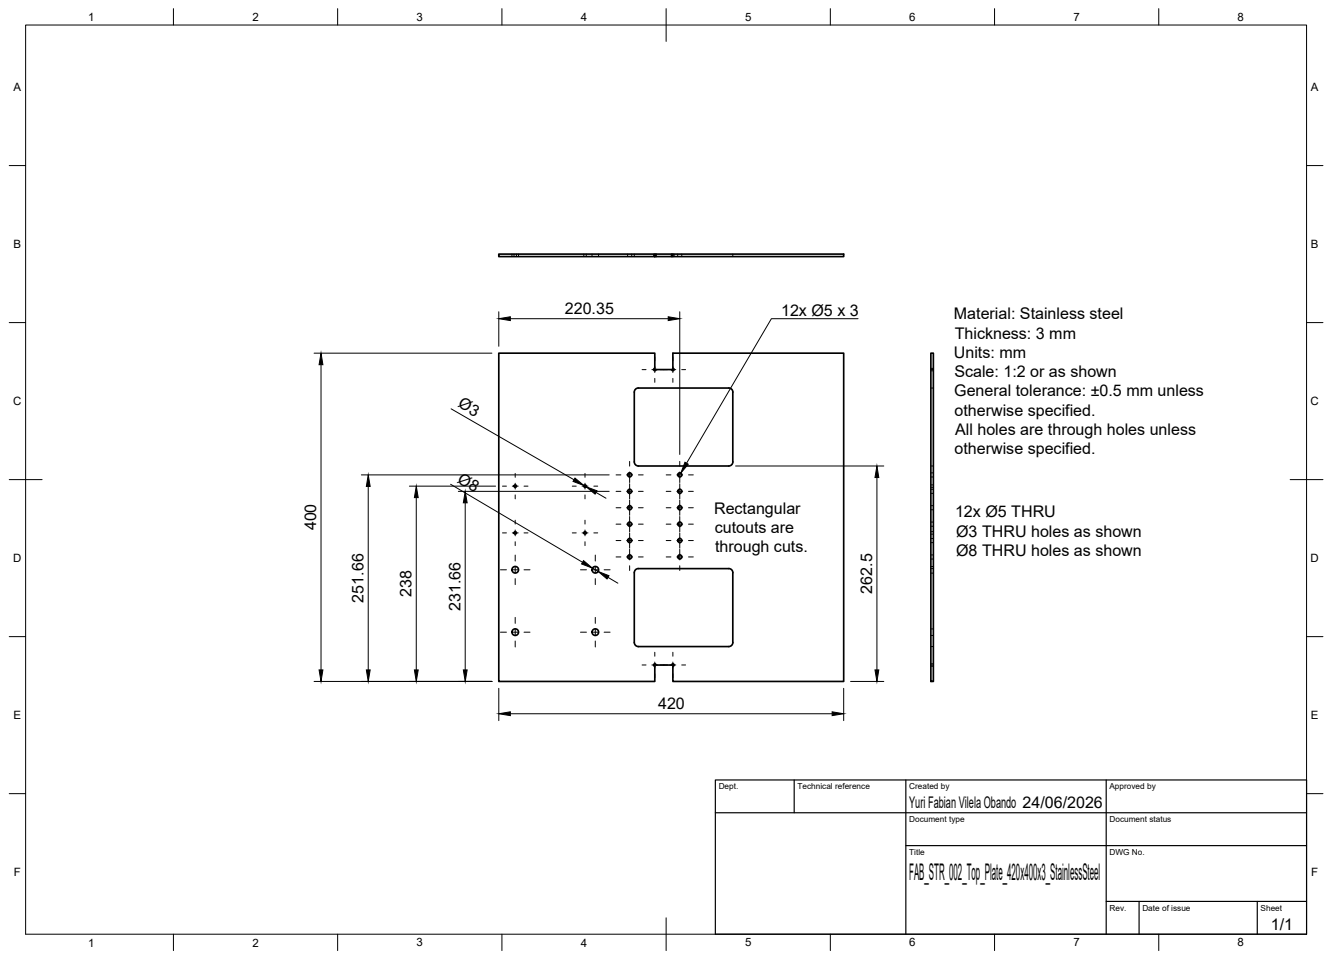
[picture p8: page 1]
Title; DWG No.; Rev.; Date of issue; Sheet; Material: Stainless steel; cutouts are through cuts.

Thickness: 3 mm
Units: mm
Scale: 1:2 or as shown
General tolerance: ±0.5 mm unless
otherwise specified.
All holes are through holes unless

12x Ø5 THRU
Ø3 THRU holes as shown
Ø8 THRU holes as shown

Dept. | Technical reference | Created by Yuri Fabian Vilela Obando 24/06/2026 | Approved by

Document type | Document status

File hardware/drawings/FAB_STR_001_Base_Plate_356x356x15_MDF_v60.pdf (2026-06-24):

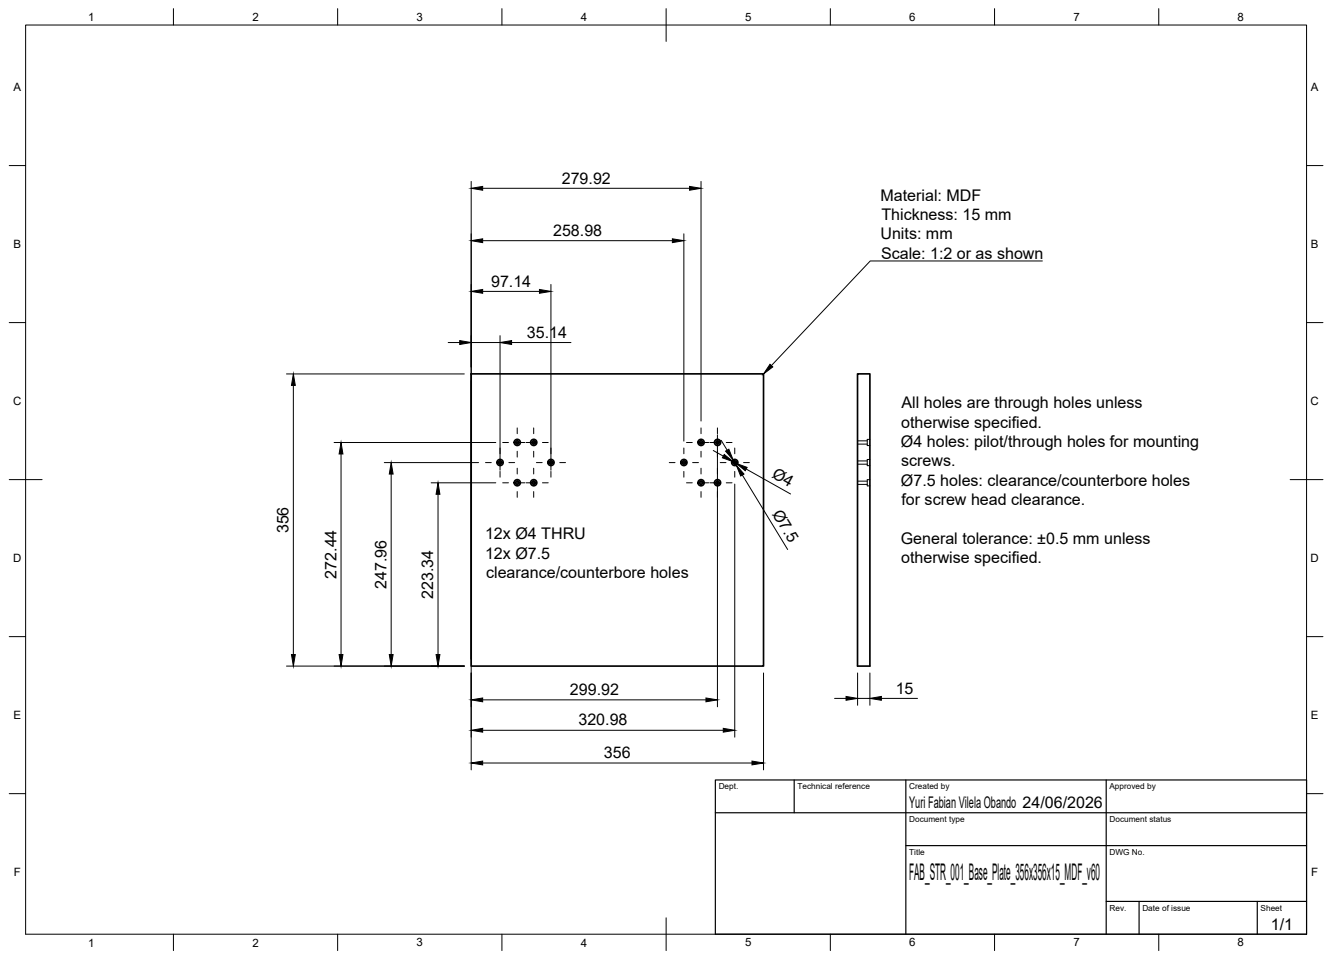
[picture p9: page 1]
Title; DWG No.; Rev.; Date of issue; Sheet; 12x Ø4 THRU 12x Ø7.5 clearance/counterbore holes

Material: MDF
Thickness: 15 mm
Units: mm
Scale: 1:2 or as shown

All holes are through holes unless
otherwise specified.
Ø4 holes: pilot/through holes for mounting
screws.
Ø7.5 holes: clearance/counterbore holes
for screw head clearance.

General tolerance: ±0.5 mm unless

Dept. | Technical reference | Created by Yuri Fabian Vilela Obando 24/06/2026 | Approved by

Document type | Document status

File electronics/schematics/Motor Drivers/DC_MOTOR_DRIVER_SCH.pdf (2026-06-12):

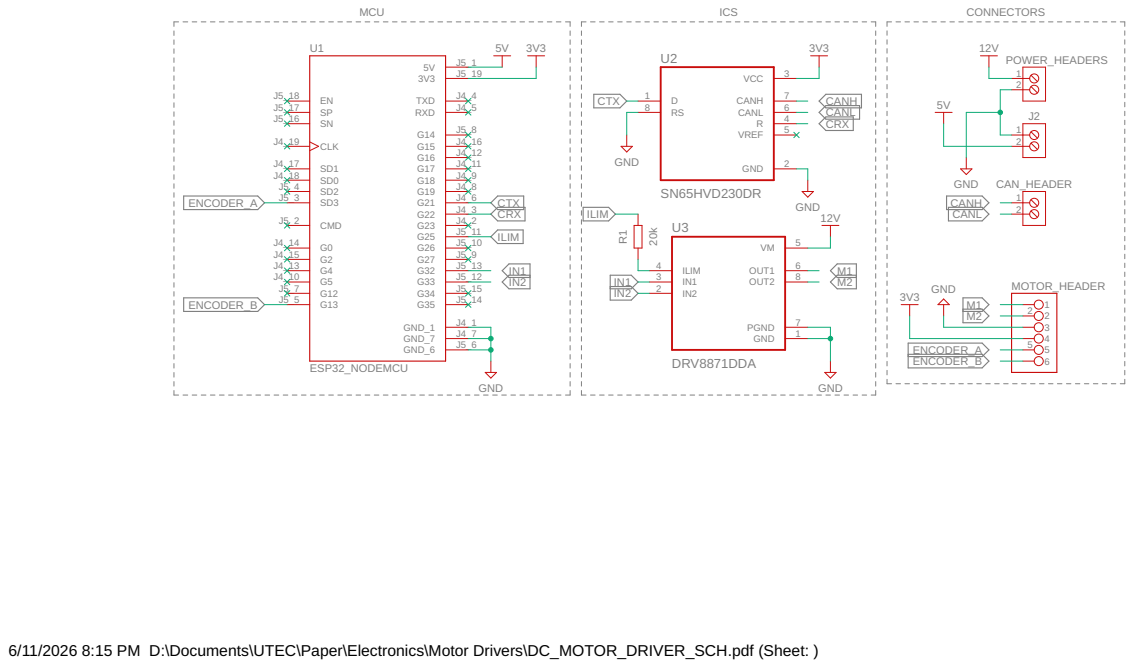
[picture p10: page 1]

6/11/2026 8:15 PM D:\Documents\UTEC\Paper\Electronics\Motor Drivers\DC_MOTOR_DRIVER_SCH.pdf (Sheet: )

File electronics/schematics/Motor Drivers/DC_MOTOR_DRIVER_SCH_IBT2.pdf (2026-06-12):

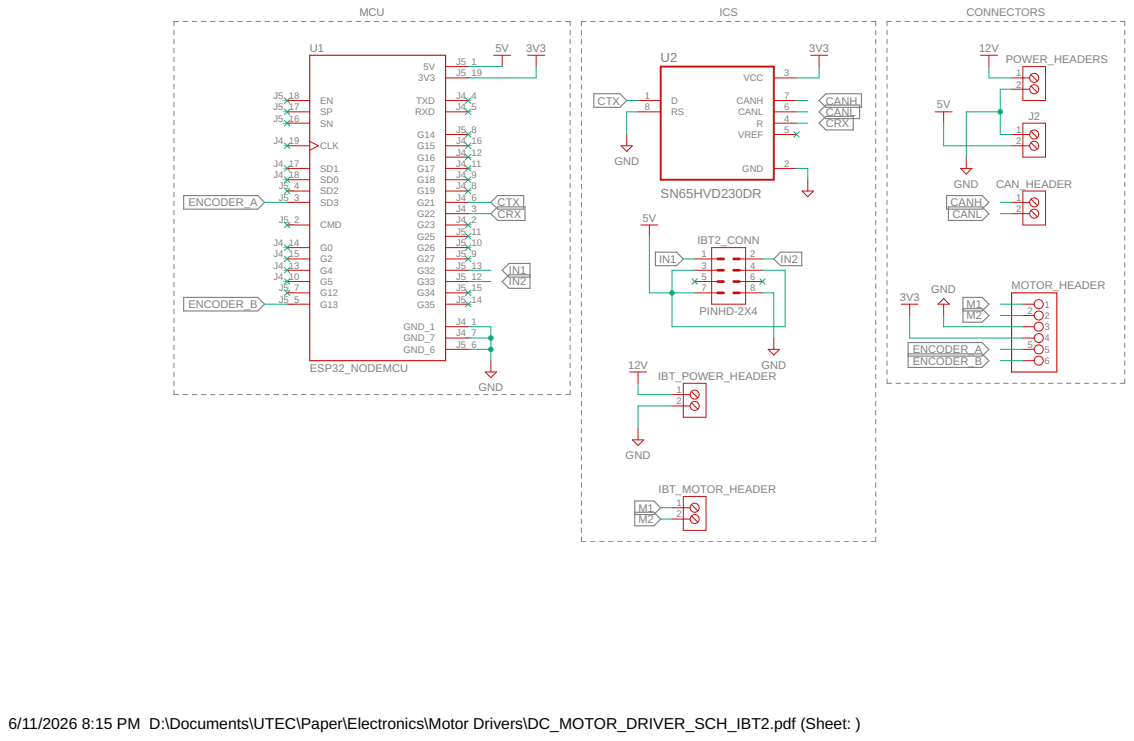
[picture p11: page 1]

6/11/2026 8:15 PM D:\Documents\UTEC\Paper\Electronics\Motor Drivers\DC_MOTOR_DRIVER_SCH_IBT2.pdf (Sheet: )

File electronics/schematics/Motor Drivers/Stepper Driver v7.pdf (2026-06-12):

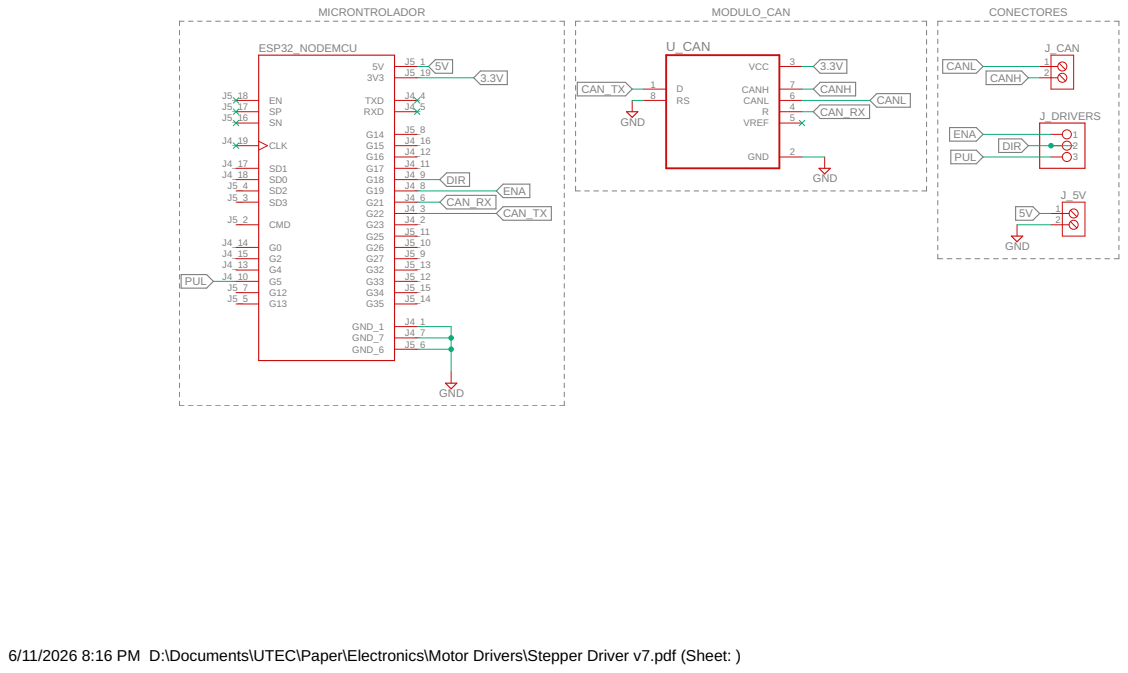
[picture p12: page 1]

6/11/2026 8:16 PM D:\Documents\UTEC\Paper\Electronics\Motor Drivers\Stepper Driver v7.pdf (Sheet: )

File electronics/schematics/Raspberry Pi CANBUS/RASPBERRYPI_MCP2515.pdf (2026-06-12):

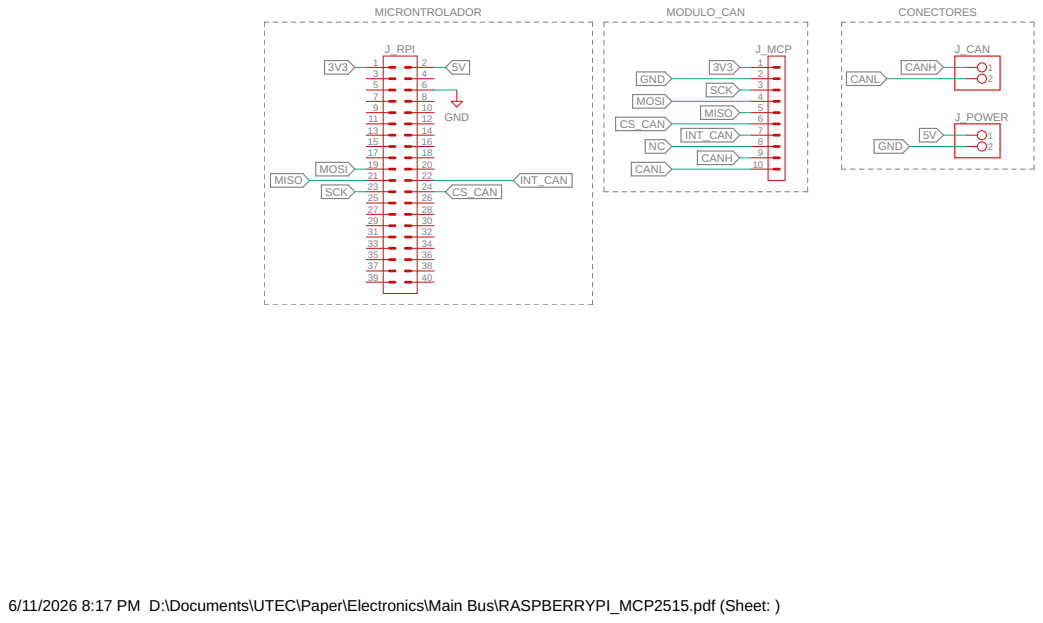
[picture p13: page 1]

6/11/2026 8:17 PM D:\Documents\UTEC\Paper\Electronics\Main Bus\RASPBERRYPI_MCP2515.pdf (Sheet: )

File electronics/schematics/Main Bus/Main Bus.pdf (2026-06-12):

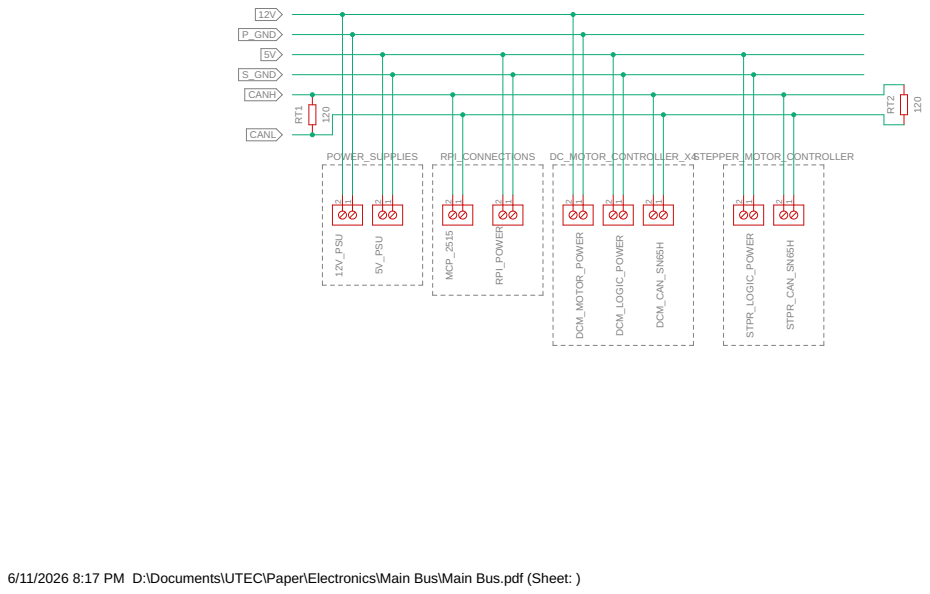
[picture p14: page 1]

6/11/2026 8:17 PM D:\Documents\UTEC\Paper\Electronics\Main Bus\Main Bus.pdf (Sheet: )

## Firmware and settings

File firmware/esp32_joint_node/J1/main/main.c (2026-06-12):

/*
 * PFC II - Asistbelle
 *
 * Modular DC motor controller.
 */

/*
 * This is the firmware for our modular DC motor controller intended for robotics.
 * This module controls a single DC motor equipped with a quadrature encoder.
 * It communicates via CANBUS (TWAI) and implements three controllers:
 * 1. An inner PI velocity controller for joint velocity
 * 2. An outer P + ff controller for joint trajectory tracking.
 * 3. A servo controller for a servo-equipped end effector.
 * It can switch between joint trajectory tracking mode (P + ff) and differential control mode (just joint velocity)
 */

/* --------------------- Libraries ------------------ */

#include "motor_driver.h"
#include "encoder_driver.h"
#include "pid_controller.h"
#include "twai_comms.h"


/* --------------------- Global variables ------------------ */

// Global process variable struct
SystemState global_pv = {0};

// Global setpoint struct
SystemState global_sp = {0};

// Global external loop setpoint struct
SystemState global_ext_sp = {0};

// Global control mode
uint32_t control_mode = 0;

// Global control effort
float u = 0.0F;


StatePointers ext_loop_ptrs = {
    .pv = &global_pv,
    .sp = &global_ext_sp,
    .control_mode = &control_mode,
    .u = &u
};

StatePointers int_loop_ptrs = {
    .pv = &global_pv,
    .sp = &global_sp,
    .control_mode = &control_mode,
    .u = &u
};

// Global TWAI message struct
twai_message_t* state_response = NULL;

// TWAI pointers
twai_task_pointers_t twai_task_pointers = {0};

// Encoder pointers
encoder_task_pointers_t encoder_task_ptrs = {0};

// Global pcnt unit handle
pcnt_unit_handle_t pcnt_unit_h = NULL;


void app_main(void)
{
    // Create mutexes
    pv_semaphore = xSemaphoreCreateMutex();
    sp_semaphore = xSemaphoreCreateMutex();
    ext_sp_semaphore = xSemaphoreCreateMutex();



    #ifdef NODE_HAS_GRIPPER
        // Initialize gripper
        gripper_init();
        gripper_write(0.0f);
    #endif

    // Initialize TWAI
    state_response = twai_message_init(ID_STATE_RESPONSE);
    
    
    // Pack twai pointers
    twai_task_pointers.msg_ptr = state_response;
    twai_task_pointers.state_ptrs = &ext_loop_ptrs;

    twai_driver_install(&g_config, &t_config, &f_config);
    twai_start();
    // Create task on core 1
    xTaskCreatePinnedToCore(twai_task, "TWAI", TWAI_TASK_STACK_DEPTH, (void*)&twai_task_pointers, TWAI_TASK_PRIO, NULL, 1);
    ESP_LOGI(MAIN_TASK_TAG, "TWAI Started.");

    // Initialize motor driver
    driver_init();
    // Create task on core 0
    xTaskCreatePinnedToCore(motor_driver_task, "Driver", DRIVER_TASK_STACK_DEPTH, (void*)&u, DRIVER_TASK_PRIO, NULL, 0);
    ESP_LOGI(MAIN_TASK_TAG, "Motor Driver Started.");

    // Initialize encoder
    // Pack encoder pointers
    encoder_task_ptrs.pcnt_unit_h = pcnt_unit_h;
    encoder_task_ptrs.system_state = &global_pv;

    encoder_init(&encoder_task_ptrs);

    // Create task on core 0
    xTaskCreatePinnedToCore(encoder_task, "Encoder", ENCODER_TASK_STACK_DEPTH, (void*)&encoder_task_ptrs, ENCODER_TASK_PRIO, NULL, 0);
    ESP_LOGI(MAIN_TASK_TAG, "Encoder Started.");


    // Create PID velocity controller task on core 0
    xTaskCreatePinnedToCore(pid_controller_task, "PID", PID_TASK_STACK_DEPTH, (void*)&int_loop_ptrs, PID_TASK_PRIO, NULL, 0);
    ESP_LOGI(MAIN_TASK_TAG, "PID Velocity controller started");

    ESP_LOGI(MAIN_TASK_TAG, "Starting main in 2s.");
    vTaskDelay(pdTICKS_TO_MS(2000));
    ESP_LOGI(MAIN_TASK_TAG, "Controller started in trajectory tracking mode");
    


    // Outer control loop
    
    float position_goal = 0.0F;
    float velocity_goal = 0.0F;

    float position_gain = TRAJ_CONTROLLER_GAIN;//4.5F;
    float max_vel = CONTROLLER_MAX_VELOCITY;

    float current_pos = 0.0F;


    while(true){
        if(xSemaphoreTake(pv_semaphore, 0)){
            current_pos = global_pv.position;

            xSemaphoreGive(pv_semaphore);
            if(xSemaphoreTake(ext_sp_semaphore, 0) && xSemaphoreTake(sp_semaphore, 0)){
                position_goal = global_ext_sp.position;
                velocity_goal = global_ext_sp.velocity;
                xSemaphoreGive(ext_sp_semaphore);

                float e = position_goal-current_pos;
                
                // If robot in differential control mode just call velocity controller
                global_sp.velocity = velocity_goal;

                // If robot in trajectory tracking mode implement P + ff trajectory tracking controller
                if(!control_mode) global_sp.velocity += position_gain*e;

                // Saturation
                if(global_sp.velocity > max_vel) global_sp.velocity = max_vel; 
                if(global_sp.velocity < -max_vel) global_sp.velocity = -max_vel; 
            
                xSemaphoreGive(sp_semaphore);
            }
        }else continue;

        vTaskDelay(pdTICKS_TO_MS(100));
        }
    }


   

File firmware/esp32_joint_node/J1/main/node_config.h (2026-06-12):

#ifndef NODE_CONFIG_H
#define NODE_CONFIG_H

#include "base_libs.h"

// Debug tags

    #define MAIN_TASK_TAG "MAIN"
    #define TWAI_TAG "TWAI"
    #define CONTROLLER_TAG "Control"
    #define DRIVER_TAG "Driver"

// Task config
    
    // Motor driver task
        #define DRIVER_TASK_STACK_DEPTH 2048
        #define DRIVER_TASK_PRIO (configMAX_PRIORITIES-10)
        
    // Encoder task
        #define ENCODER_TASK_STACK_DEPTH 2048
        #define ENCODER_TASK_PRIO (configMAX_PRIORITIES-11)

    // PID Controller task
        #define PID_TASK_STACK_DEPTH 2048
        #define PID_TASK_PRIO (configMAX_PRIORITIES-12)

    // TWAI task
        #define TWAI_TASK_STACK_DEPTH 4096    
        #define TWAI_TASK_PRIO (configMAX_PRIORITIES-13)
    

// Motor Driver
    // Driver IN pins
    #define DRV_IN1 GPIO_NUM_32
    #define DRV_IN2 GPIO_NUM_33
    

    // If the ILIM pin of the driver is connected or not
    // Comment out if not
    #define ILIM_CONNECTED //J1 has ILIM

    // Measured value of ILIM Resistor
    #define ILIM_RESISTOR 45.44F //kOhm 



// Encoder
    // J2
    #define ENCODER_A_PIN GPIO_NUM_10
    #define ENCODER_B_PIN GPIO_NUM_13
    #define ENCODER_PPR 68.0F
    #define GEAR_REDUCTION 131.0F // Motor gearbox
    
    // Flip encoder
    //#define ENCODER_FLIP

    #define VELOCITY_FILTER_CONSTANT 0.01F
    #define FILTER_FREQUENCY 1000

// Controller
    #define CONTROLLER_FREQUENCY 500
    #define CONTROLLER_GAIN_KP 200.0F
    #define CONTROLLER_GAIN_KI 15.0F
    #define CONTROLLER_INTEGRATOR_LIMIT 90.0F
    #define CONTROLLER_GAIN_KD 0.0F
    #define CONTROLLER_MAX_VELOCITY (5.0F*M_PI)

// Trajectory controller
    #define TRAJ_CONTROLLER_GAIN 20.0F


// TWAI

    // SN65H pins
        // J2
        #define TX_GPIO_NUM GPIO_NUM_21
        #define RX_GPIO_NUM GPIO_NUM_22
        

    // TWAI Address
        //J4
        #define DEVICE_ID               0x001
        #define ID_STATE_REQUEST        0x0A1
        #define ID_STATE_BROADCAST_REQUEST 0x0A6

        #define ID_STATE_RESPONSE       0x0B1
        
        #define ID_SETPOINT_CHANGE      0x0C1
        
        #define ID_CONTROL_MODE         0x0D1



    // Gripper
        // J1 has no gripper
        // #define NODE_HAS_GRIPPER
        
        
        #ifdef NODE_HAS_GRIPPER
            // Gripper cmd
            #define ID_GRIPPER_CMD          0x0D2
            // Gripper pin
            #define GRIPPER_PIN GPIO_NUM_5
        #endif //NODE_HAS_GRIPPER


#endif // NODE_CONFIG_H

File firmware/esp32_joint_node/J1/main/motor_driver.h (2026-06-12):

#ifndef MOTOR_DRIVER_H
#define MOTOR_DRIVER_H

// Driver for DRV8871 H-bridge.

// Base libraries
#include "base_libs.h"

// Node config
#include "node_config.h"


// MCPWM driver
#include "driver/mcpwm.h"


#ifdef ILIM_CONNECTED
// If ILIM resistor is connected, set DAC to output a fixed voltage to set current limit

    // DAC libraries
    #include "driver/dac_oneshot.h"
    
    // Full scale current limit. Max. 3.6
    #define I_FS 3.5F

    
    // Driver constants
    #define VRREF 1.232F //V
    #define VILIM 64.0F //V
    #define ARREF VILIM
    #define RREF ILIM_RESISTOR

    // I FS = ARREF * (VRREF - VDAC)/(VRREF * RREF)
    #define VDAC (-(I_FS*VRREF*RREF - ARREF*VRREF)/ARREF)

    // DAC handle
    #define DAC_CHANNEL DAC_CHAN_0
    dac_oneshot_handle_t dac = NULL;

    // DAC setup function
    esp_err_t setup_dac(dac_oneshot_handle_t* dac){
        esp_err_t error = ESP_OK;
        dac_oneshot_config_t config = {};
        config.chan_id = DAC_CHANNEL;
        error = dac_oneshot_new_channel(&config, dac);
        if(error != ESP_OK) return error;
        error = dac_oneshot_output_voltage(*dac, ((uint8_t)(VDAC)) );
        return error;
    }

#endif


// Motor direction struct
typedef enum {
    DIR_FORWARD = 0,
    DIR_BACKWARD,
    DIR_BRAKE,
    DIR_COAST
} motor_dir_t;


// MCPWM config
    #define PWM_FREQ_HZ        20000   // 20 kHz PWM
    #define MCPWM_UNIT_USED    MCPWM_UNIT_0
    #define MCPWM_TIMER_USED   MCPWM_TIMER_0
    #define MCPWM_OP_A         MCPWM0A
    #define MCPWM_OP_B         MCPWM0B


// ===== Initialize driver =====
esp_err_t driver_init(void)
{   esp_err_t error = ESP_OK;

    
    // Initialize MCPWM GPIOs
    error = mcpwm_gpio_init(MCPWM_UNIT_USED, MCPWM0A, DRV_IN1);
    error = mcpwm_gpio_init(MCPWM_UNIT_USED, MCPWM0B, DRV_IN2);
    if(error != ESP_OK) return error;

    // Configure MCPWM
    mcpwm_config_t pwm_config = {
        .frequency = PWM_FREQ_HZ,       // frequency
        .cmpr_a = 0.0,                  // duty cycle of operator A
        .cmpr_b = 0.0,                  // duty cycle of operator B
        .duty_mode = MCPWM_DUTY_MODE_0, // active high
        .counter_mode = MCPWM_UP_COUNTER, // up counter
    };

    error = mcpwm_init(MCPWM_UNIT_USED, MCPWM_TIMER_USED, &pwm_config);

    // Brake motor at first
    mcpwm_set_signal_high(MCPWM_UNIT_USED, MCPWM_TIMER_USED, MCPWM_GEN_A);
    mcpwm_set_signal_high(MCPWM_UNIT_USED, MCPWM_TIMER_USED, MCPWM_GEN_B);

    // If ILIM connected, setup DAC and output fixed voltage
    #ifdef ILIM_CONNECTED
        if(error != ESP_OK) return error;
        error = setup_dac(&dac);
    #endif

    return error;
}


void driver_write(float normalized_effort)
{
    // Writes to driver via MCPWM peripheral
    
    // Direction
    motor_dir_t dir;
    if(normalized_effort > 0) {
        dir = DIR_FORWARD;
    }else if(normalized_effort < 0){
        dir = DIR_BACKWARD;
    }else{
            // Brake for direct position control
            dir = DIR_BRAKE;     

            // Coast for velocity control
            //dir = DIR_COAST;
        }

    // Saturation
    if (normalized_effort < -100.0F) normalized_effort = -100.0F;
    if (normalized_effort > 100.0F) normalized_effort = 100.0F;
    
    switch (dir) {
        case DIR_FORWARD:
            // A = PWM, B = Low
            mcpwm_set_signal_low(MCPWM_UNIT_USED, MCPWM_TIMER_USED, MCPWM_GEN_B); 
            mcpwm_set_duty(MCPWM_UNIT_USED, MCPWM_TIMER_USED, MCPWM_GEN_A, fabsf(normalized_effort));
            mcpwm_set_duty_type(MCPWM_UNIT_USED, MCPWM_TIMER_USED, MCPWM_GEN_A, MCPWM_DUTY_MODE_0);
            break;

        case DIR_BACKWARD:
            // B = PWM, A = Low
            mcpwm_set_signal_low(MCPWM_UNIT_USED, MCPWM_TIMER_USED, MCPWM_GEN_A);
            mcpwm_set_duty(MCPWM_UNIT_USED, MCPWM_TIMER_USED, MCPWM_GEN_B, fabsf(normalized_effort));
            mcpwm_set_duty_type(MCPWM_UNIT_USED, MCPWM_TIMER_USED, MCPWM_GEN_B, MCPWM_DUTY_MODE_0);
            break;

        case DIR_BRAKE:
            // Both high (brake)
            mcpwm_set_signal_high(MCPWM_UNIT_USED, MCPWM_TIMER_USED, MCPWM_GEN_A);
            mcpwm_set_signal_high(MCPWM_UNIT_USED, MCPWM_TIMER_USED, MCPWM_GEN_B);
            break;

        case DIR_COAST:
        default:
            // Both low (coast)
            mcpwm_set_signal_low(MCPWM_UNIT_USED, MCPWM_TIMER_USED, MCPWM_GEN_A);
            mcpwm_set_signal_low(MCPWM_UNIT_USED, MCPWM_TIMER_USED, MCPWM_GEN_B);
            break;
    }
}



void motor_driver_task(void* data){
    
    // Write control effor to driver at high frequency
    float* u = (float*)data;
    
    
    while (true){

        driver_write(*u);
        vTaskDelay(pdMS_TO_TICKS(1));

    }
    

}

#endif //MOTOR_DRIVER_H

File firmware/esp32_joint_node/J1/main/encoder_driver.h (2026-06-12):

#ifndef ENCODER_DRIVER_H
#define ENCODER_DRIVER_H

// Driver for motor encoder.

// Base libraries
#include "base_libs.h"

// Node config
#include "node_config.h"

// PCNT Unit
#include "driver/pulse_cnt.h"


// PCNT Configs
#define PCNT_HIGH_LIMIT 10000
#define PCNT_LOW_LIMIT  -10000

#define SAMPLE_RATE (((float)1)/((float)FILTER_FREQUENCY))
#define MS_PER_LOOP (int)(1000/FILTER_FREQUENCY)

#define COUNTS_TO_RAD (float)((2.0F*M_PI)/(ENCODER_PPR*GEAR_REDUCTION))


// Helper struct
typedef struct
{
    SystemState* system_state;
    pcnt_unit_handle_t pcnt_unit_h;
} encoder_task_pointers_t;


void encoder_init(encoder_task_pointers_t* ptrs){

    // Initialize encoder

    // Configure GPIO


    // configure GPIO input + pullups
    gpio_config_t io_conf = {
        .pin_bit_mask = (1ULL << ENCODER_A_PIN) | (1ULL << ENCODER_B_PIN),
        .mode = GPIO_MODE_INPUT,
        .pull_up_en = GPIO_PULLUP_ENABLE,
        .pull_down_en = GPIO_PULLDOWN_DISABLE,
        .intr_type = GPIO_INTR_DISABLE
    };
    gpio_config(&io_conf);



    pcnt_unit_config_t unit_config = {
        .low_limit = PCNT_LOW_LIMIT,
        .high_limit = PCNT_HIGH_LIMIT,
        .flags.accum_count = true
    };

    // Create PCNT unit on handle
     pcnt_new_unit(&unit_config, &(ptrs->pcnt_unit_h));

     

    // Set glitch filter
    pcnt_glitch_filter_config_t filter_config = {
        .max_glitch_ns = 10000,
    };

     pcnt_unit_set_glitch_filter(ptrs->pcnt_unit_h, &filter_config);
     

    // Configure channels
    pcnt_chan_config_t chan_a_config = {
        .edge_gpio_num = ENCODER_A_PIN,
        .level_gpio_num = ENCODER_B_PIN,
    };

    pcnt_channel_handle_t pcnt_chan_a = NULL;
    pcnt_new_channel(ptrs->pcnt_unit_h, &chan_a_config, &pcnt_chan_a);
    
    pcnt_channel_handle_t pcnt_chan_b = NULL;
    pcnt_chan_config_t chan_b_config = {
        .edge_gpio_num = ENCODER_B_PIN,
        .level_gpio_num = ENCODER_A_PIN,
    };
    pcnt_new_channel(ptrs->pcnt_unit_h, &chan_b_config, &pcnt_chan_b);
    

    // Set edge and level actions
        pcnt_channel_set_edge_action(pcnt_chan_a, PCNT_CHANNEL_EDGE_ACTION_INCREASE, PCNT_CHANNEL_EDGE_ACTION_DECREASE);
        pcnt_channel_set_level_action(pcnt_chan_a, PCNT_CHANNEL_LEVEL_ACTION_KEEP, PCNT_CHANNEL_LEVEL_ACTION_INVERSE);
        pcnt_channel_set_edge_action(pcnt_chan_b, PCNT_CHANNEL_EDGE_ACTION_DECREASE, PCNT_CHANNEL_EDGE_ACTION_INCREASE);
        pcnt_channel_set_level_action(pcnt_chan_b, PCNT_CHANNEL_LEVEL_ACTION_KEEP, PCNT_CHANNEL_LEVEL_ACTION_INVERSE);

    
    // Install watchpoints for count rollover
    int watch_points[] = {PCNT_LOW_LIMIT, 0, PCNT_HIGH_LIMIT};
    for (size_t i = 0; i < sizeof(watch_points)/sizeof(watch_points[0]); ++i) {
        pcnt_unit_add_watch_point(ptrs->pcnt_unit_h, watch_points[i]);
    }
     

    // Start unit
     pcnt_unit_enable(ptrs->pcnt_unit_h);
     pcnt_unit_clear_count(ptrs->pcnt_unit_h);
     pcnt_unit_start(ptrs->pcnt_unit_h);

}

void encoder_task(void* data){

    // Get pointers
    encoder_task_pointers_t* ptrs = (encoder_task_pointers_t*)data;

    // Process variable pointer
    SystemState* pv = (SystemState*)ptrs->system_state;
    

    // Define constants with arithmetic as variables so macros aren't recalculated each time
    const float counts_to_rad = COUNTS_TO_RAD;
    const float sample_rate = SAMPLE_RATE;
    const float ms_per_loop = MS_PER_LOOP;
    const float alpha = VELOCITY_FILTER_CONSTANT;

    // Initialize count
    int count = 0;
    int previous_count = 0;
    int count_delta = 0;
    float counts_per_second = 0.0F;

    // Loop counter and timer
    int loops_since_last_change = 0;
    float dt = 0.0F;

    // Velocity filter
    float decay = 0.001F;

    float prev_position = 0.0F;
    float position = 0.0F;
    float raw_velocity = 0.0F;
    float velocity = 0.0F;

    // Task timing
    TickType_t xLastWakeTime;
    xLastWakeTime = xTaskGetTickCount();
    while (1) {
        
        // Read count
        pcnt_unit_get_count((ptrs->pcnt_unit_h), &count);
    
        #ifdef ENCODER_FLIP
            count *= -1.0F;
        #endif

        // Calculate angular position
        position = ((float)count)*counts_to_rad;
        
        

        // Calculate delta
        count_delta = count - previous_count;
        previous_count = count;

        if(count_delta != 0){
            // Motor moved between loops.

            // dt is by default loop time times number of loops since last change
            dt = loops_since_last_change * sample_rate;

            // If it's zero (plus leeway for fp precision) it's the sample rate
            if(dt < 1e-6f) dt = sample_rate;

            // Calculate counts per second
            counts_per_second = ((float)count_delta)/dt;

            // Calculate raw velocity
            raw_velocity = counts_per_second*counts_to_rad;

            // Filter
            velocity = alpha*velocity + (1.0F-alpha)*raw_velocity;

            // Since we moved, reset loops since last movement
            loops_since_last_change = 0;
        }else{
            // No movement between loops
            loops_since_last_change++;

            // Exponential decay
            velocity *= expf(-decay*sample_rate);

            // Filter
            velocity = alpha*velocity + (1.0F-alpha)*raw_velocity;

        }
        

        // Hybrid velocity filter 


        // rad/s
        raw_velocity = (position-prev_position)*((float)(FILTER_FREQUENCY));

        prev_position = position;

        // Velocity first order filter
        velocity = alpha*velocity + (1.0F-alpha)*raw_velocity;
        
        // Update global variables
        
        if(xSemaphoreTake(pv_semaphore, pdMS_TO_TICKS(ms_per_loop/2.0F))){
            // Try to update position and velocity.
            // If pv is blocked for more than filter cycle time, discard old measurement and measure again
            
            pv->position = position;
            


            pv->velocity = velocity;
            //pv->velocity = raw_velocity;
            xSemaphoreGive(pv_semaphore);
        }

        // Fixed time task
        vTaskDelayUntil(&xLastWakeTime,pdMS_TO_TICKS(ms_per_loop));
    }
}



#endif //ENCODER_DRIVER_H

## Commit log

2026-06-12 Initial HardwareX package for Assistbelle arm and elevator subsystem
    [bom_template.csv, j5_motion_summary.csv, pick_and_place_summary.csv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]
2026-06-12 Added schematics
    Added electronics schematics for project
2026-06-12 Add schematics index for HardwareX electronics documentation
2026-06-12 Update schematics README with navigation and review criteria
2026-06-12 Update HardwareX checklist with current electronics status
2026-06-15 Update README for HardwareX arm and elevator subsystem scope
2026-06-15 Update power distribution summary with final supply architecture
2026-06-15 Update controller node driver assignments and validation checklist
2026-06-15 Add connector table template for electronics verification
2026-06-15 Update electronics README with connector table and power status
2026-06-15 Update schematics index from uploaded PDF schematics
2026-06-15 Update connector table with data extracted from schematic PDFs
2026-06-15 Update schematics README with reviewed PDF coverage
2026-06-16 Update main bus wiring documentation from schematic review
2026-06-16 Update Raspberry Pi MCP2515 voltage documentation
2026-06-16 Clarify MCP2515 5V implementation in schematics README
2026-06-16 Update connector table MCP2515 voltage note
2026-06-16 Add public procurement log from purchase documents
    [purchase_log_public.csv]
2026-06-16 Add structural profiles and fasteners reconciliation table
    [structural_profiles_table.csv]
2026-06-16 Update fasteners README with V-slot reconciliation status
2026-06-16 Update procurement reconciliation with user-confirmed V-slot and IBT-2 usage
2026-06-16 Mark structural profiles and threaded rod as user-confirmed active
    [structural_profiles_table.csv]
2026-06-16 Add user-confirmed V-slot 2020 brackets and threaded rod to BOM
    [bom_template.csv]
2026-06-24 Add final HardwareX elevator BOM CSV from Google Sheet
    [hardwarex_elevator_bom_final.csv]
2026-06-24 Add BOM README with source traceability
2026-06-24 Reference final HardwareX BOM export in procurement README
2026-06-24 Update project status to use final v54 HardwareX BOM
2026-06-24 Add readable Markdown version of HardwareX elevator BOM
2026-06-24 Link readable Markdown BOM from BOM README
2026-06-24 Update root README to point to final HardwareX BOM
2026-06-24 Add CAD electronics components to final BOM
    [hardwarex_elevator_bom_final.csv]
2026-06-24 Update readable BOM with CAD electronics components
2026-06-24 Update root README after adding CAD electronics to BOM
2026-06-24 Update project status after adding CAD electronics to BOM
2026-06-24 Update BOM README after adding CAD electronics
2026-06-24 Sync final BOM CSV from updated Google Sheet
    [hardwarex_elevator_bom_final.csv]
2026-06-24 Sync readable BOM Markdown from updated Google Sheet
2026-06-24 Update BOM README from latest Google Sheet sync
2026-06-24 Update root README from latest BOM sync
2026-06-24 Update project status from latest BOM sync
2026-06-24 Update procurement README from latest BOM sync
2026-06-24 Add Git LFS tracking for CAD and media files
2026-06-24 Document Git LFS workflow for large CAD uploads
2026-06-24 Add Fusion 360 elevator assembly v54
    [ASM_Elevator_System_v54.f3z]
2026-06-24 Limit Git LFS tracking to CAD and heavy media
2026-06-24 Add STEP elevator assembly v54
    [ASM_Elevator_System_v54.step]
2026-06-24 Rename current elevator CAD snapshot to v60
    [ASM_Elevator_System_v60.f3z, ASM_Elevator_System_v60.step]
2026-06-24 Update design upload plan to current v60 snapshot
2026-06-24 Update hardware README after v60 CAD upload
2026-06-24 Add STL NEMA23 mounting plate v60
    [FAB_ACT_002_NEMA23_Mounting_Plate_ABS_v60.stl]
2026-06-24 Mark NEMA23 mounting plate STL as uploaded
2026-06-24 Add STL spacer block v60
    [FAB_GUI_002_Spacer_Block_ABS_Gray_v60.stl]
2026-06-24 Add drawing base plate v60
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2026-06-25 Update gantry plate dimensions in BOM CSV
    [hardwarex_elevator_bom_final.csv]
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2026-06-25 Update gantry plate drawing target dimensions in design index
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2026-06-25 Add DXF fabrication files v60
    [FAB_GUI_001_Gantry_Plate_127x88x3_StainlessSteel_v60.dxf, FAB_STR_002_Top_Plate_420x400x3_StainlessSteel_v60.dxf]
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2026-06-25 Update power summary with confirmed emergency and J5 notes
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2026-06-25 Track WebM and Tracker validation artifacts with LFS
2026-06-25 Add curated validation datasets and tracker files
    [j1_ramp_30.0deg_5reps.csv, j1_step_30.0deg_5reps.csv, j1_trap_30.0deg_5reps.csv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]
2026-07-03 Clean up stray dev artifacts in ros2_ws
    - Remove ros2_ws/sudo, an accidentally committed empty file.
    - Move ad-hoc IK debug scripts (calc_pose4.py, test_loop_ik.py,
    verify_can_node.py) out of the can_comm_pkg package root into
    tools/, alongside the existing dh_inspector.py.
    - Move a one-off trajectory CSV/plot output into tools/sample_outputs/
    instead of the package root.
    - Fix verify_can_node.py: it imported can_comm_pkg.can_node and hardcoded
    a personal machine path (/home/rosario/...) from before the core/ apps/
    reorganization; now imports can_comm_pkg.core.can_node and resolves its
    path relative to the script.
2026-07-03 Add ROS 2 clean-clone build CI
    README.md and docs/repository_audit.md both list "ROS 2 compiles from a
    clean clone" and "validate all ROS 2 entry points" as open closure items
    that are currently checked by hand. Add a GitHub Actions workflow that
    builds can_comm_pkg with colcon on ros:jazzy-ros-base for every push/PR
    touching ros2_ws/, plus a fast py_compile syntax pass and colcon test.
    Add the resulting status badge to the README.
    Intentionally scoped to can_comm_pkg only (matches the documented Quick
    start), and does not attempt to build the ESP-IDF firmware in CI: per
    firmware/ESP_IDF_BUILD_GUIDE.md, J1-J4 firmware is still missing some
    source files needed to compile standalone, so a fir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
2026-10-23 Add Demo section to README with validation clips
    Recruiters and reviewers skim the top of the README; until now it had no
    image of the robot. The section shows the arm on the vertical elevator, a
    joint 1 step test and the perception result, all cut from the existing
    laboratory validation recordings so nothing new is claimed.
    GIFs are trimmed, cropped and palette-reduced (1.3 MB and 0.8 MB) and live
    under validation/media/readme/, tracked by LFS like the rest of the media.
